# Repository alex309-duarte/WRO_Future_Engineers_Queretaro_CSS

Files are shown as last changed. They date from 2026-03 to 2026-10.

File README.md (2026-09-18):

# CSS - WRO Future Engineers 2026

This repository contains the engineering documentation for **CSS**'s autonomous vehicle for the **WRO Future Engineers**, 2026 season. Our team is based in Querétaro, México.

---

## Table of Contents

1. [Our Team](#our-team)
2. [Challenge Overview](#challenge-overview)
3. [Our Robot](#our-robot)
   - [3.1 Mobility Management](#mobility-management)
   - [3.2 Power & Sense Management](#power-sense-management)
   - [3.3 Obstacle Management & Control Strategy](#obstacle-management)
4. [Engineering Process & Design Iterations](#engineering-process)
5. [Construction Guide](#construction-guide)
6. [Bill of Materials (BOM)](#bom)
7. [Repository Structure](#repository-structure)
8. [Setup & Execution Instructions](#setup-instructions)
9. [Driving Videos](#driving-videos)
10. [Resources & References](#resources)
11. [License](#license)

---

## 1. Our Team 
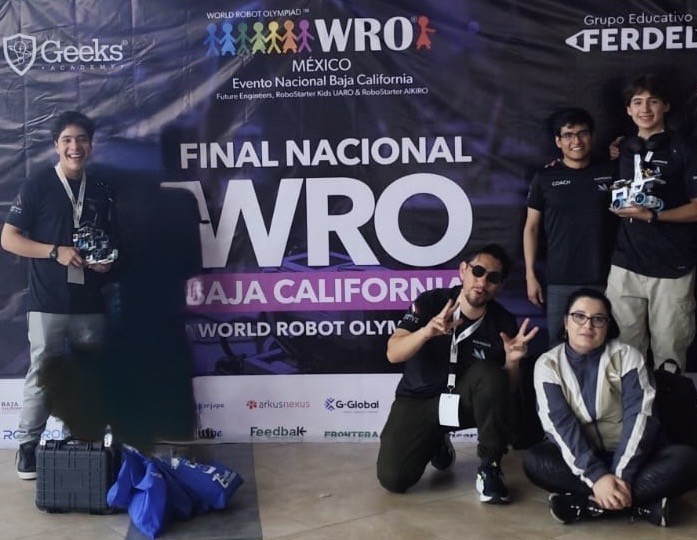
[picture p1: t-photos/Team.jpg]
<br>
***Disclaimer:***
*This image has been edited to remove former team members who are no longer part of the project, in order to protect their privacy. Editing was done using Microsoft Photos' generative erase feature.*

### Team Members

#### Christian Gael Centeno Velez
**Age:** 17\
**Role:** Captain. Software, electronics and mechanical design\
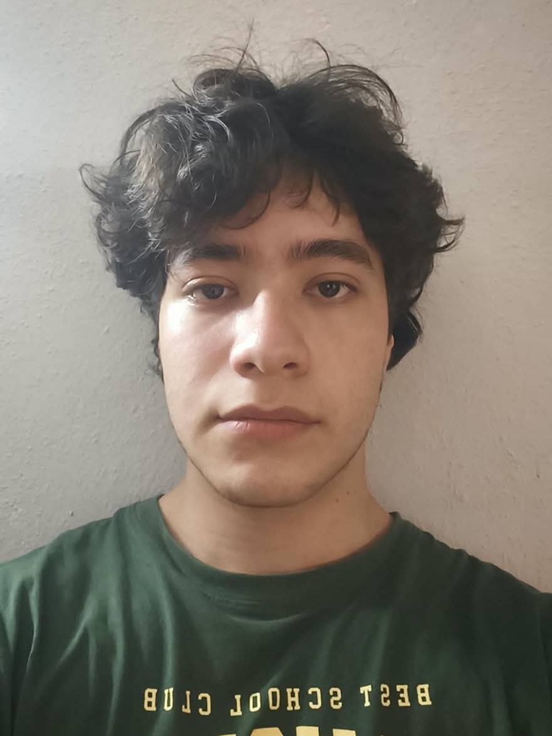
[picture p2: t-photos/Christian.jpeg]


>I am currently in my senior year of high school at the Colegio de Estudios Científicos y Tecnológicos del Estado de Querétaro (CECyTEQ), specializing as a Mechatronics Technician. I have a strong background in competitive robotics, having participated in previous editions of the World Robot Olympiad (WRO). In 2024, I competed in the RoboMission category, and in 2025, I secured third place at the national level in the Future Engineers category. Through my years of experience competing in the WRO, I have developed solid skills in robot programming, design, and electronics.

#### Sebastián Esquivel Mondragón
**Age:** 18\
**Role:** Documentation, electronics and mechanical design\
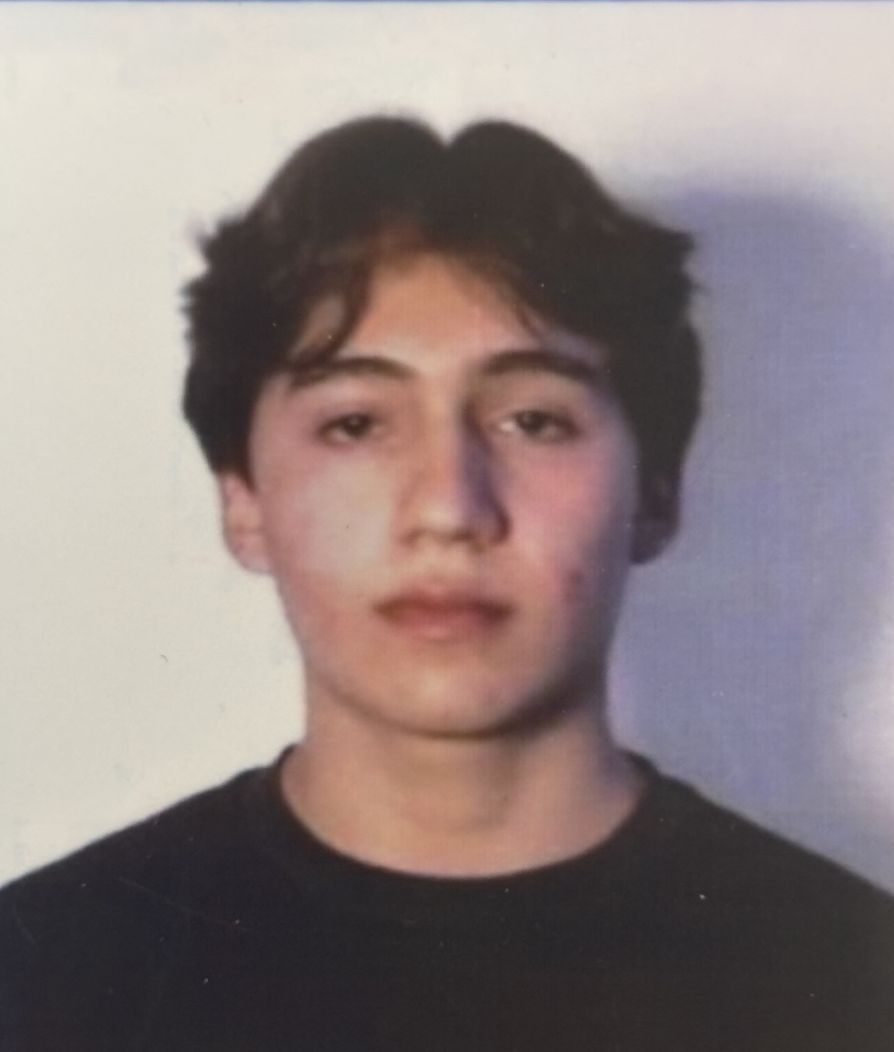
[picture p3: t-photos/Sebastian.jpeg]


> Currently pursuing a Bachelor of Science in Mechatronics Engineering at Monterrey Institute of Technology and Higher Education (ITESM), on an academic talent scholarship. My background in robotics began in middle school with the MekLab Robotics team (UAQ), where I competed in WRO RoboMission, placing 3rd nationally in 2022 (Junior) and 2nd nationally in 2023 (Senior), qualifying for the international final in Panama. In 2025, our now independent and disaffiliated team moved into WRO Future Engineers, placing 2nd nationally. Most of my software and electronics experience comes from these competitions. I've also worked as an intern at GS de México (GS Global), in the Research and Development (R&D) department, where I further developed CAD design skills and many other engineering competencies, such as problem solving skills, now applied towards this project.

---

### Coach and other members

#### Manuel Alejandro Cardoso Duarte
**Age:** 27\
**Role:** Coach\
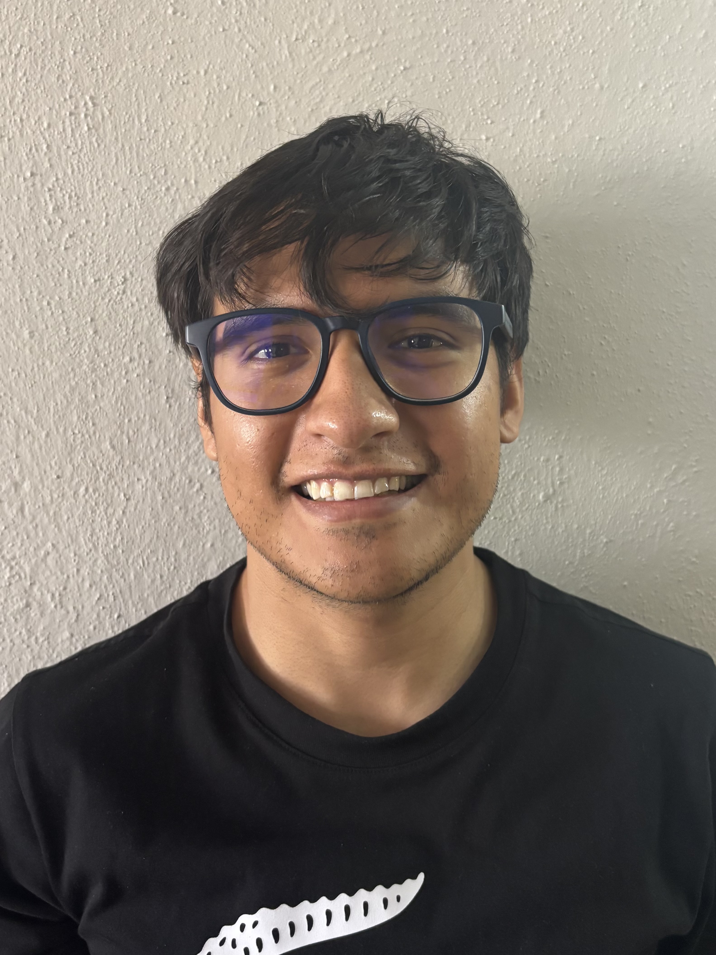
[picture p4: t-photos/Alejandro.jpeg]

> Bachelor of Technology from the Universidad Nacional Autónoma de México (UNAM), Centro de Física Aplicada y Tecnología Avanzada (CFATA), and currently works as an Embedded Software Engineer at KOSTAL Automotive Services Mexicana, developing AUTOSAR-based embedded software (C, CAN/LIN bus communication, memory stack integration) for automotive door control modules serving clients such as Stellantis, FORD, and Rivian. His background in robotics coaching spans since February 2018, guiding high school teams at the Facultad de Ingeniería, Universidad Autónoma de Querétaro (UAQ) through the World Robot Olympiad, including leading our team to the 2023 international final in Panama City and to a national podium finish in RoboMission. As coach, his role is to teach the underlying engineering and programming concepts (Python, C, embedded systems) and guide the team's problem-solving process, without building or programming the vehicle himself. For more information visit: [CV Alejandro](other/additionalMedia/Others/CV_Manuel_Alejandro_Cardoso_Duarte_2026-compressed.pdf)

---

#### José de Jesús Santana Ramírez, M.Sc.
**Age:** 40\
**Role:** Assistant coach\
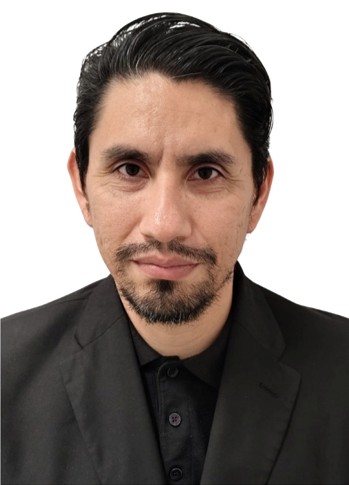
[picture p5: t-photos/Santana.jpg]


>Mechatronics Engineer and Master of Science in Instrumentation and Control, with a solid track record in teaching, technological development, and innovation-oriented engineering applications. Currently pursuing a Ph.D. in Computer Science, focusing on research areas related to artificial intelligence, neural networks, computational modeling of physical systems, and control of mechanical systems. His expertise integrates hardware and software development for robotics, automation, and embedded systems projects. He serves as the coordinator of the Center for Studies in Robotics and Sciences (CEROC) at UAQ, as well as a professor in the Space Engineering degree program at ENES-UNAM. His professional profile is distinguished by connecting academic training, applied research, and a commitment to the scientific and technological education of future generations.
---

#### Rocío Damara Merlo Espino, Ph.D.
**Age:** 36\
**Role:** Administrative project manager\
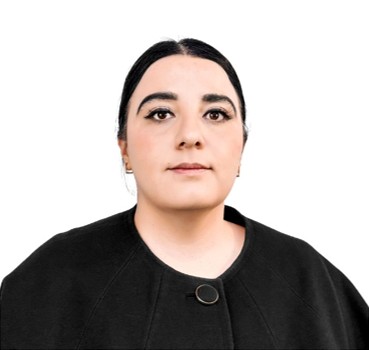
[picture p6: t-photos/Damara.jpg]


>Academic Degrees:
>- Bachelor’s Degree in Psychology, Educational concentration.
>- Specialization in School Learning.
>- Master’s Degree in Innovation in Virtual Teaching-Learning Environments.
>- Ph.D. in Educational Technology.
>
>Professional with a background in Psychology, School Learning, Innovation in Virtual Teaching-Learning Environments, and Educational Technology. She is the co-leader of the international chapter Women in Robotics Querétaro, Mexico, and brings over 12 years of experience in educational robotics, science pedagogy, and scientific outreach. Currently, she is completing a postdoctoral fellowship in Quality Management Systems for Engineering and Space Industry Laboratories at the High Technology Unit of the Faculty of Engineering at UNAM. In addition, she is a professor of Aerospace Engineering at ENES Juriquilla, a researcher, and Head of the Outreach Department at the Center for Studies in Robotics and Sciences (CEROC) at UAQ. She has driven academic, scientific, and technological projects, as well as student development in STEAM competencies.

---

## 2. Challenge Overview 

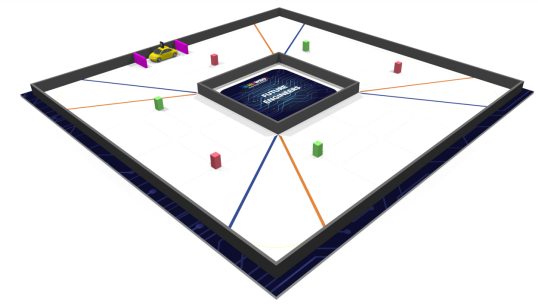
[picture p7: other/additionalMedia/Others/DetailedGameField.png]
Detailed Game Field


The **WRO Future Engineers** challenge requires teams to build a fully autonomous vehicle capable of completing both of the following challenges:

### Open Challenge
The vehicle must complete three laps on the track with random placements of the inside track walls.

### Obstacle Challenge
The vehicle must complete three laps on the track while detecting and avoiding randomly placed coloured obstacles (either green or red blocks), passing them on a specific side according to their colour, and then finish by performing a parallel parking maneuver.

More info: [WRO Official Site](https://wro-association.org/) | [Future Engineers Rules](other/WRO-2026-FE_GeneralRules.pdf)

---

## 3. Our Robot 

**Robot name:** ***"The Maker"***

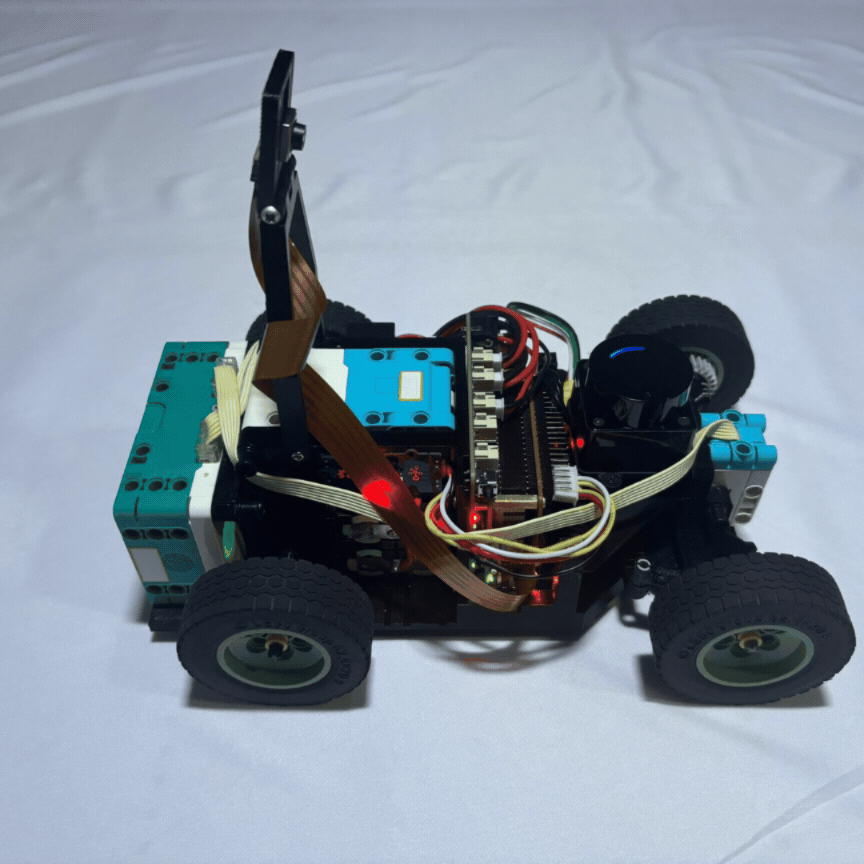
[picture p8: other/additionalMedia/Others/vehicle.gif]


<table style="width:100%">

<tr>

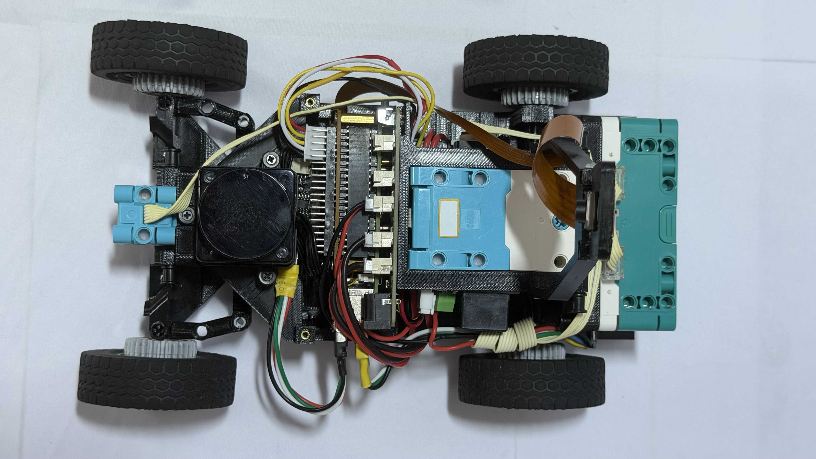
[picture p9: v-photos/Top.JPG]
<td align="center"><br>Top</td>

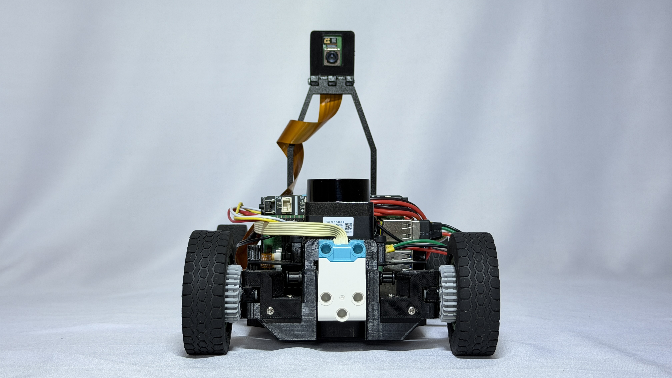
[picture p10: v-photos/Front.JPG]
<td align="center"><br>Front</td>

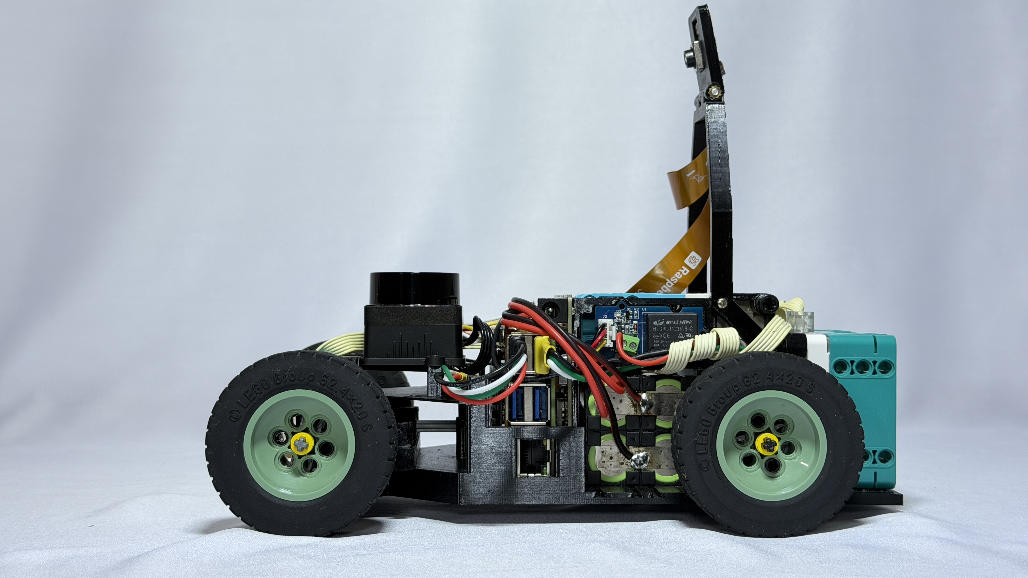
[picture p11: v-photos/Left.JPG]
<td align="center"><br>Left</td>

</tr>

<tr>

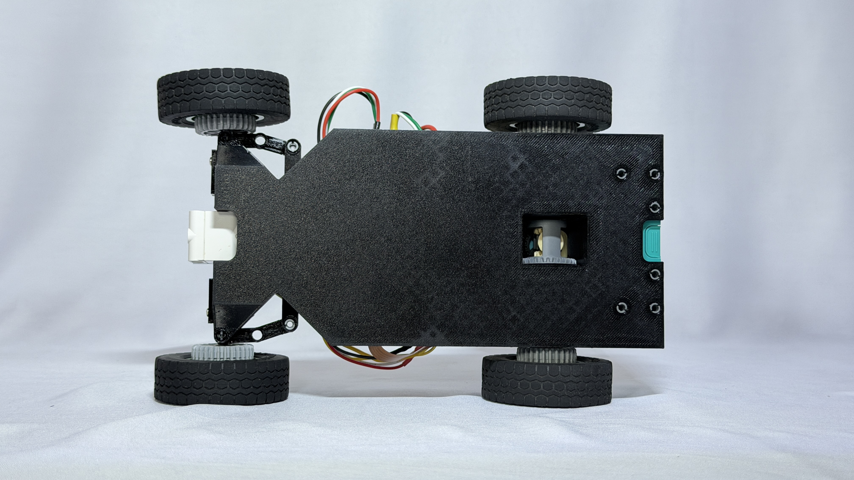
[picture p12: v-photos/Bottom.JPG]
<td align="center"><br>Bottom</td>

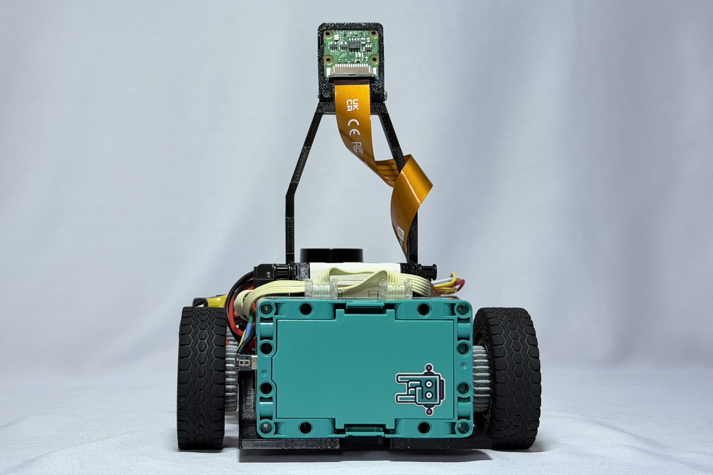
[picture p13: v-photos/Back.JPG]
<td align="center"><br>Back</td>

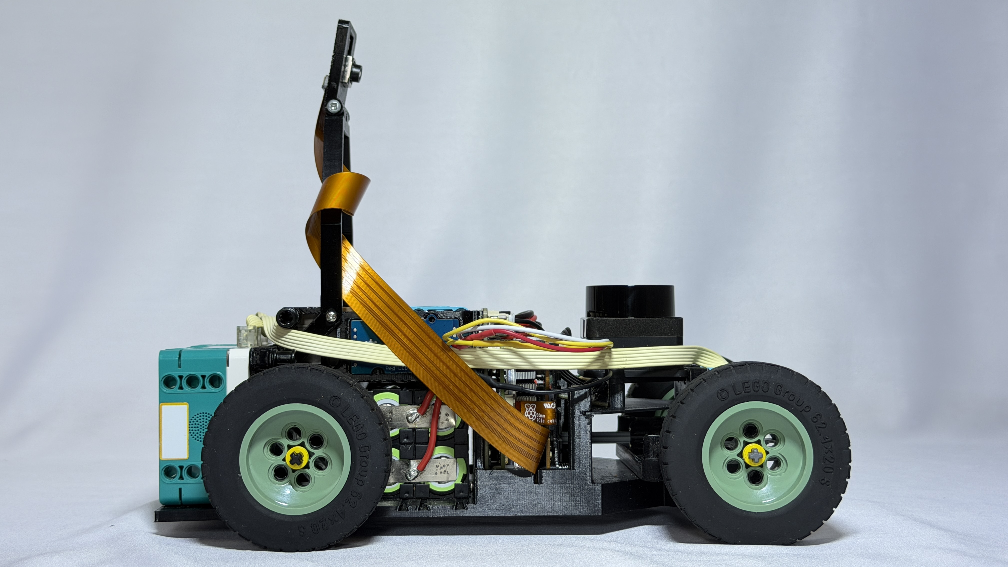
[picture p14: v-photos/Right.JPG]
<td align="center"><br>Right</td>

</tr>

</table>

***"The Maker"*** is a rear-wheel-drive autonomous vehicle built around a fully custom, in-house 3D-printed chassis (designed in SolidWorks, printed on a Creality K1C) that repositions the battery pack and most components lower in the frame to lower the center of gravity and reduce weight transfer through corners. This year's chassis also trades the sharper-turning custom double-Ackermann steering geometry used in last year's prototype for a simpler regular-Ackermann, a deliberate trade-off made after trial and error showed the reliability gain outweighed the small loss in turning radius. A single LEGO SPIKE Large Angular Motor drives the rear axle while a LEGO SPIKE Small Angular Motor actuates the Ackermann steering, both commanded by a LEGO SPIKE Prime Hub, whose built-in IMU also supplies the robot's heading. Perception comes from a Orbbec Oradar MS200k LiDAR fused with a Raspberry Pi Camera Module 3 Wide accelerated by a Raspberry Pi AI HAT+ 2 (Hailo-10H, 40 TOPS). The LiDAR handles wall-following and obstacle range, the camera tracks the obstacles using a custom-trained YOLOv8n model (trained on our own labeled dataset and compiled to the Hailo-10H's `.hef` format) and classifies pillar colour, and this year's design drops the ultrasonic sensors, now using only the LiDAR and camera. All control and vision code runs in C/C++ on a Raspberry Pi 5, migrated from last year's Python codebase specifically to cut processing latency, and the whole robot is considerably lighter and more power-efficient than its predecessor: a smaller steering motor, a lighter AI/camera replacing an OAK-D Lite, and a 4-cell battery pack (down from 6 cells) sized to match the lower power draw.

### 3.1 Mobility Management 

#### Steering System

The Maker's steering uses a regular Ackermann linkage, achieving a maximum steering angle of **45.44°**. This geometry ensures the inner and outer front wheels trace concentric arcs around a common turning center during a turn, minimizing tire scrub and keeping the front tires rolling rather than dragging through corners, a property that matters directly for both consistency and tire wear over a full run.

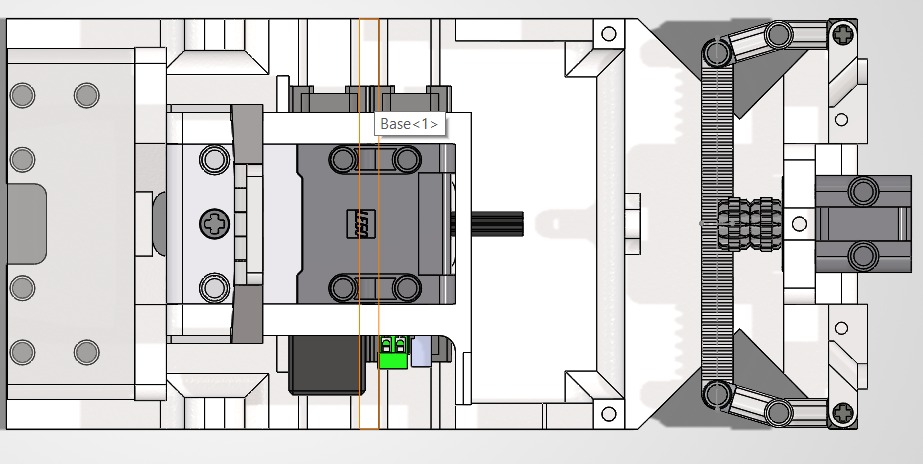
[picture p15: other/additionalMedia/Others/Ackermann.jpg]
Plan view of the current Ackermann steering system CAD model


*Figure 1. Plan view of the current Ackermann steering linkage, showing the tie-rod and knuckle geometry.*

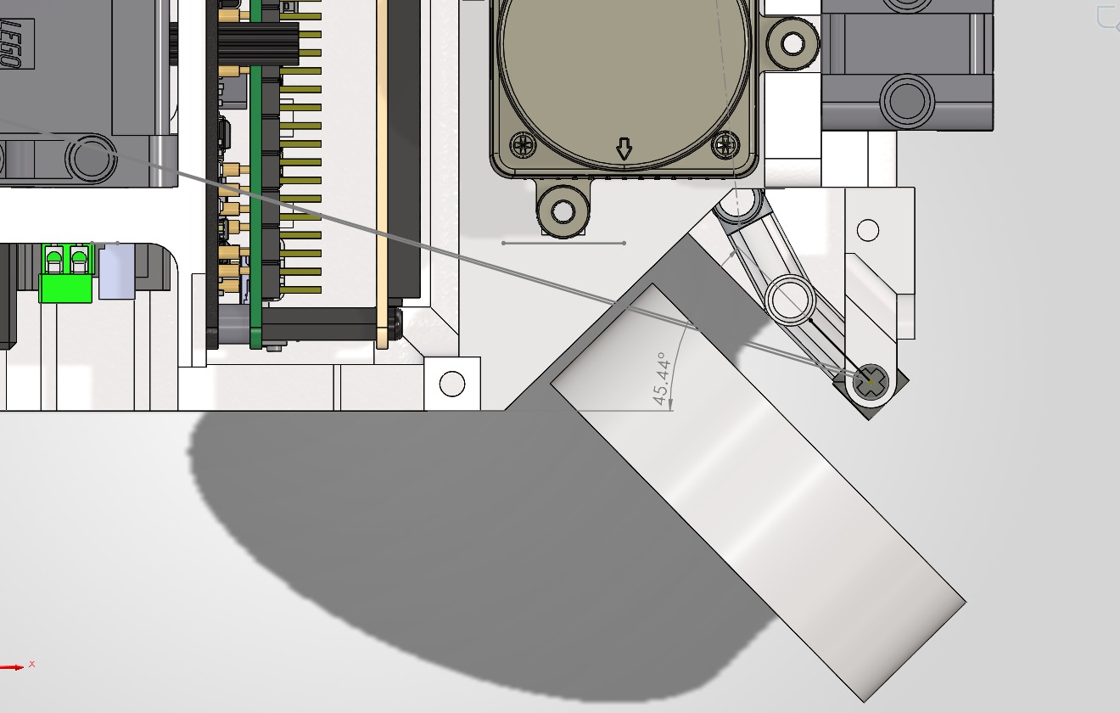
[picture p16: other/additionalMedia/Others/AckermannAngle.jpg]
CAD detail view showing the 45.44 degree Ackermann steering angle


*Figure 2. Detail view of the CAD model highlighting the achieved maximum steering angle of 45.44°.*

The Ackermann is actuated by a LEGO SPIKE Prime Small Angular Motor (Part 45607), commanded by the LEGO SPIKE Prime Hub. This is a change from previous seasons, where a medium angular motor was used: with this year's lighter chassis and reduced overall mass, the torque required to actuate the steering dropped enough that the smaller motor became sufficient, and switching to it freed up both weight and packaging space for other components.

This regular Ackermann design also represents a deliberate step back from last year's steering geometry. In the previous season, the team implemented a custom double-Ackermann linkage, which allowed for a tighter turning radius but introduced mechanical inconsistencies and reliability flaws during testing.

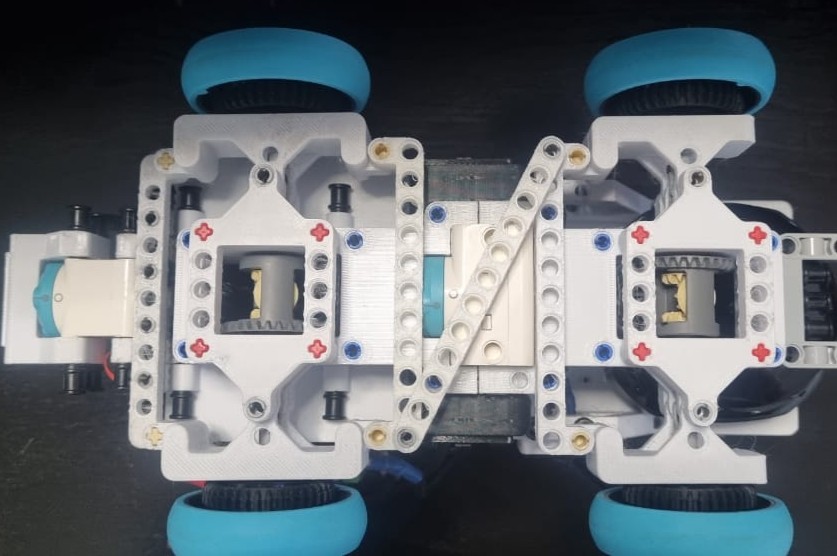
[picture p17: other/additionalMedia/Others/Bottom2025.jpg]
Bottom view of last year's robot showing the double Ackermann steering system


*Figure 3. Bottom view of the previous season's robot, showing the double-Ackermann steering configuration used last year.*

After weighing both options, the team concluded that the regular Ackermann's slightly wider turning radius was an acceptable trade-off given the reliability gained: it consistently completes every required turn on the WRO track, while eliminating the mechanical inconsistencies that affected the double-Ackermann design.

#### Drivetrain

This year's drivetrain also marks a layout change from last year's all-wheel-drive (AWD) configuration (see [Figure 3](other\additionalMedia\Others\Bottom2025.jpg)) to a rear-wheel-drive (RWD) layout. Driving only the rear axle simplified the drivetrain (removing the front differential/driveshaft hardware needed for AWD), reducing weight and mechanical complexity, while still providing enough traction for the WRO track once paired with the new LEGO 62.4×20S rubber tires.

The vehicle uses a single LEGO SPIKE Large Angular Motor (Part 45602) driving the rear axle through a $20{:}28$ gear reduction ($R = 1.4$), turning LEGO $62.4 \times 20\text{S}$ rubber tires (Part 32019) ($r = 0.0312\text{ m}$). The motor and gear ratio were not assumed, they were sized against a full dynamic torque analysis targeting $a = 0.73\text{ m/s}^2$ over $t = 0.5\text{ s}$ to reach cruising speed.
<table>
  <tr>
    <td align="center">
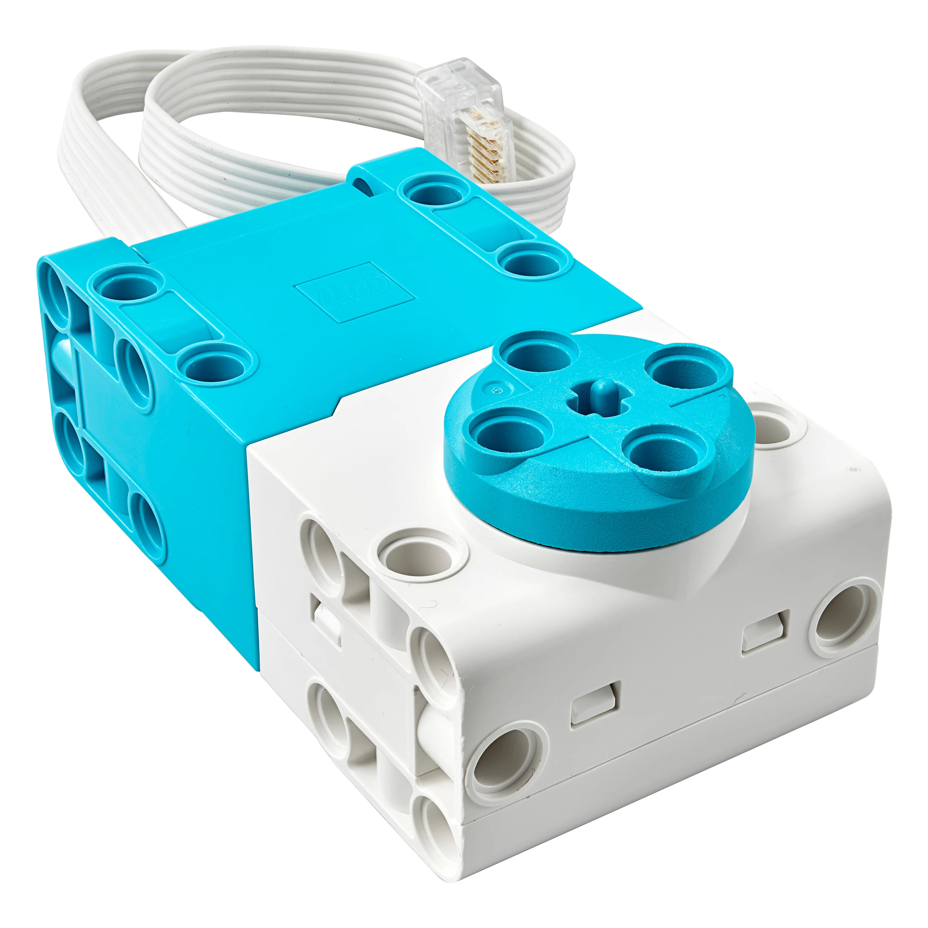
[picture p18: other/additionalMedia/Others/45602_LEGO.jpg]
      <br>
      <em>LEGO SPIKE Large Angular Motor (45602)</em>
    </td>
    <td align="center">
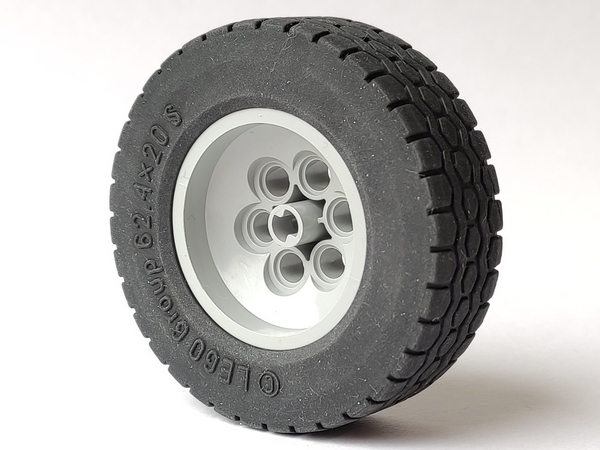
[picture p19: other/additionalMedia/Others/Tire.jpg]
      <br>
      <em>LEGO Tire 62.4 x 20 S (32019)</em>
    </td>
  </tr>
</table>

**Result:**
 at this operating point, the motor runs at only **33.8%** of its continuous max-efficiency torque capacity, reaching a loaded top speed of **0.365 m/s**, leaving a **66.2%** torque reserve for inclines or unexpected track perturbations.

> ### Full torque & speed calculations
>
> #### 1. Design Inputs & Parameters
>
> | Parameter | Symbol | Value | Unit |
> | :--- | :---: | :---: | :---: |
> | Robot Mass | $m$ | $1.006$ | $\text{kg}$ |
> | Wheel Diameter | $d$ | $0.0624$ | $\text{m}$ |
> | Wheel Radius | $r$ | $0.0312$ | $\text{m}$ |
> | Target Linear Acceleration ($t = 0.5\text{ s}$) | $a$ | $0.73$ | $\text{m/s}^2$ |
> | Rolling Resistance Coeff. (Rubber LEGO $62.4 \times 20\text{ S}$) | $C_{rr}$ | $0.03$ | -- |
> | Acceleration of Gravity | $g$ | $9.81$ | $\text{m/s}^2$ |
> | Number of Drive Motors | $N$ | $1$ | -- |
> | Gearbox Reduction Ratio ($20:28$) | $R$ | $1.4$ | -- |
> | Gearbox Efficiency | $\eta$ | $0.85$ | -- |
>
> **2. Step-by-Step Derivation**
>
> **Step 1: Linear Acceleration Force ($F_{acc}$)**
>
> $$
> F_{acc} = m \cdot a = 1.006\text{ kg} \cdot 0.73\text{ m/s}^2 = 0.7344\text{ N}
> $$
>
> **Step 2: Rolling Resistance Force ($F_{rr}$)**
>
> $$
> F_{rr} = C_{rr} \cdot m \cdot g = 0.03 \cdot 1.006\text{ kg} \cdot 9.81\text{ m/s}^2 = 0.2961\text{ N}
> $$
>
> **Step 3: Total Linear Force ($F_{total}$)**
>
> $$
> F_{total} = F_{acc} + F_{rr} = 0.7344\text{ N} + 0.2961\text{ N} = 1.0305\text{ N}
> $$
>
> **Step 4: Total Wheel Torque ($T_w$)**
>
> $$
> T_w = F_{total} \cdot r = 1.0305\text{ N} \cdot 0.0312\text{ m} = 0.03215\text{ N}\cdot\text{m}
> $$
>
> **Step 5: Nominal Motor Torque ($T_m$)**
>
> $$
> T_m = \frac{T_w}{\eta \cdot R} = \frac{0.03215\text{ N}\cdot\text{m}}{0.85 \cdot 1.4} = 0.02702\text{ N}\cdot\text{m} \quad (\approx 2.70\text{ Ncm})
> $$
>
> **Step 6: Motor Torque with Safety Factor ($T_{m,req}$)**
>
> A 25% safety margin ($1.25\times$) is applied to establish the minimum required torque of the traction motor, accounting for dynamic losses not captured above:
>
> $$
> T_{m,req} = T_m \cdot 1.25 = 0.02702\text{ N}\cdot\text{m} \cdot 1.25 = \mathbf{0.03377\text{ N}\cdot\text{m}} \quad (\approx 3.38\text{ Ncm})
> $$
>
> **3. LEGO SPIKE Large Angular Motor (45602) Analysis & Speed Derivation**
>
> **3.1 Motor Technical Specifications (9V)**
>
> | Operating Condition | Torque ($\text{N}\cdot\text{m}$) | Torque ($\text{Ncm}$) | Speed ($\text{RPM}$) | Current ($\text{mA}$) |
> | :--- | :---: | :---: | :---: | :---: |
> | No Load | 0.0000 | 0.00 | 175 ± 15% | 135 ± 15% |
> | Max Efficiency | 0.0800 | 8.00 | 135 ± 15% | 430 ± 15% |
> | Stall Limit | 0.2500 | 25.00 | 0 | 1900 ± 15% |
>
> **3.2 Motor Operating Point & Load Analysis**
>
> **Continuous Duty Load (%)** (vs. Max Efficiency Point):
>
> $$
> \text{Load}_{\text{eff}} = \frac{T_m}{T_{\text{max-eff}}} \cdot 100 = \frac{2.70\text{ Ncm}}{8.00\text{ Ncm}} \cdot 100 = \mathbf{33.8}\verb|%|
> $$
>
> **Stall Limit Margin (%)** (vs. Stall Torque):
>
> $$
> \text{Load}_{\text{stall}} = \frac{T_m}{T_{\text{stall}}} \cdot 100 = \frac{2.70\text{ Ncm}}{25.00\text{ Ncm}} \cdot 100 = \mathbf{10.8}\verb|%|
> $$
>
> **3.3 Top Speed Derivation**
>
> **Step 1: Loaded Motor RPM**
>
> $$
> \text{RPM}_{\text{motor}} = \text{RPM}_{\text{no-load}} \cdot \left(1 - \frac{T_m}{T_{\text{stall}}}\right) = 175 \cdot \left(1 - \frac{2.702\text{ Ncm}}{25.00\text{ Ncm}}\right) = 156.1\text{ RPM}
> $$
>
> **Step 2: Loaded Wheel RPM**
>
> $$
> \text{RPM}_{\text{wheel}} = \frac{\text{RPM}_{\text{motor}}}{R} = \frac{156.1\text{ RPM}}{1.4} = 111.5\text{ RPM}
> $$
>
> **Step 3: Top Loaded Linear Speed**
> $$v_{loaded} = \frac{\text{RPM}_{wheel} \cdot \pi \cdot d}{60} = \frac{111.5 \cdot \pi \cdot 0.0624}{60} = \mathbf{0.365\text{ m/s}}$$
>
> **3.4 Technical Conclusion**
>
> With $a = 0.73\text{ m/s}^2$, the robot reaches its operational cruising speed of $0.365\text{ m/s}$ in exactly $0.5\text{ s}$. Operating at only 33.8% of the motor's continuous max-efficiency capacity ensures minimal thermal build-up and low current draw, leaving a 66.2% torque reserve to absorb unexpected track perturbations.

#### Chassis Design

The chassis is a fully custom, in-house design, modeled in SolidWorks and 3D-printed on a Creality K1C. This is a continuation of the team's own-design approach from previous years, refined for this iteration to package the electronics more densely and lower the center of gravity, positioning the battery pack and most of the main components lower in the frame.

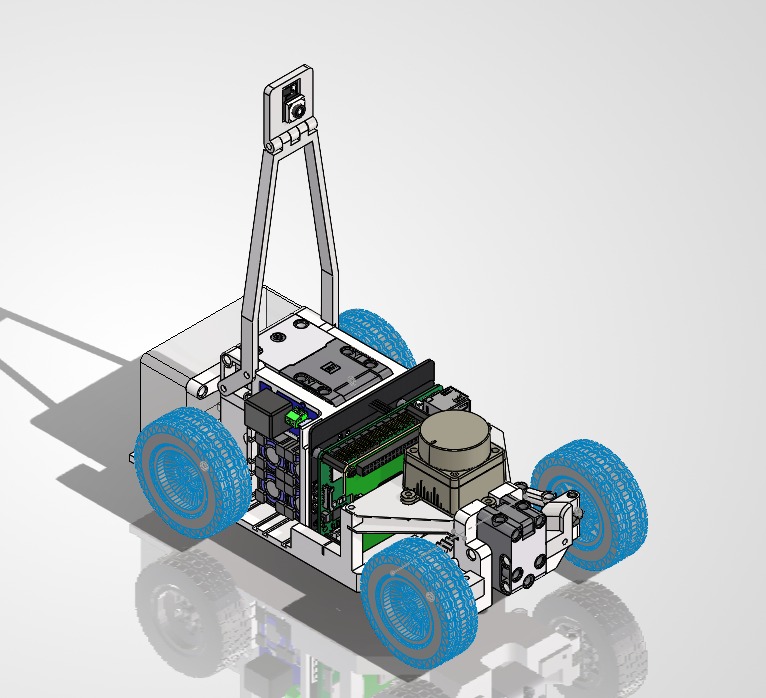
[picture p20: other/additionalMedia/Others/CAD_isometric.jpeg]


*Figure 4. Isometric view of the current chassis CAD model.*

#### Assembly & Balance

Repositioning the battery pack and heavier components (Raspberry Pi 5, UPS shield, LiDAR) lower in the frame was a deliberate choice to lower the chassis's center of gravity, reducing lateral weight transfer during high-speed cornering and improving mechanical traction without altering the Ackermann geometry itself. Component placement was also driven by the switch to a smaller, lighter camera/AI stack (Hailo-10H + Camera Module 3 Wide, replacing the OAK-D Lite) and a lighter 2-cell battery pack (replacing the previous 3-cell pack), both of which reduced overall mass and allowed tighter, more balanced packaging than in previous prototypes.

---

### 3.2 Power & Sense Management 

### Sensors & Perception Units

---

**Orbbec Oradar MS200k LiDAR**
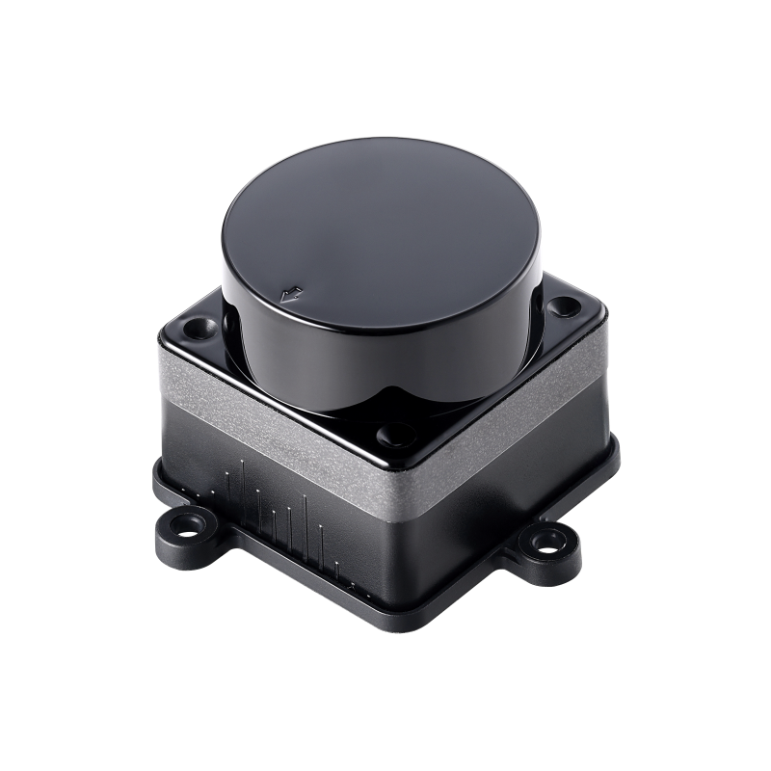
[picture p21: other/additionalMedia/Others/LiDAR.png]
<br><br>
Provides a 360° distance scan around the robot, used for wall-following (perpendicular distance and orientation of the walls relative to the robot) and for measuring range to obstacles once they've been located by the camera. It replaces last year's Slamtec RPLiDAR S2L: after trial and error, it was chosen for being lighter and giving more reliable, less noisy distance readings. It connects to the Raspberry Pi 5 and feeds the wall-detection/line-fitting logic that drives the robot's navigation decisions.

---

**Raspberry Pi Camera Module 3 Wide + Raspberry Pi AI HAT+ (Hailo-10H, 40 TOPS)**
<table>
  <tr>
    <td align="center">
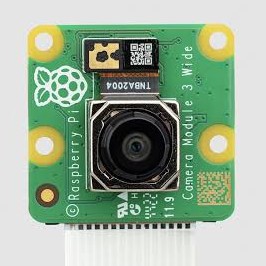
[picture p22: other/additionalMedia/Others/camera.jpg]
      <br>
      <em>Raspberry Pi Camera Module 3 Wide</em>
    </td>
    <td align="center">
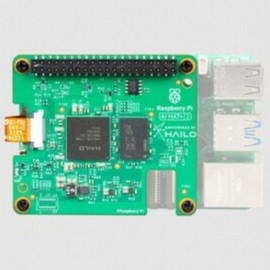
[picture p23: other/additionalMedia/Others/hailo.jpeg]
      <br>
      <em>Raspberry Pi AI HAT+ 40 TOPS (Hailo-10H)</em>
    </td>
  </tr>
</table>
The camera captures the visual feed used to detect obstacle pillars and classify their color (red/green), while the Hailo-10H accelerator runs a custom-trained YOLOv8n model on-device to perform that detection/classification in real time. This pairing replaces last year's OAK-D Lite, chosen to reduce weight, power consumption, and response (inference) time while increasing overall efficiency. The camera's detections are fused with the LiDAR's distance data: the camera identifies what an obstacle is and roughly where, and the LiDAR supplies the precise distance needed to compute an avoidance vector.

---

**LEGO SPIKE Prime Hub (built-in IMU)**
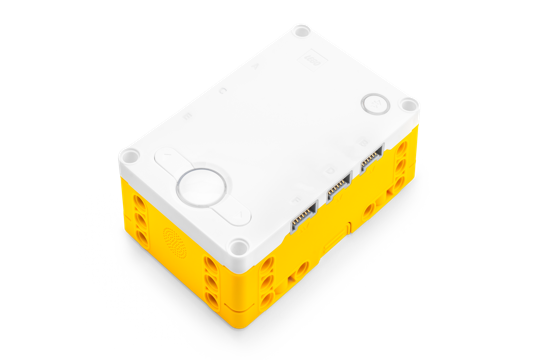
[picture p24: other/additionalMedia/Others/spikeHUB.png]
<br><br>
Rather than using a separate IMU module, the team relies on the SPIKE Prime Hub's built-in IMU to supply the robot's heading/orientation. The hub communicates with the Raspberry Pi 5 over a serial link, both relaying IMU readings and receiving motor commands for the drivetrain and steering.

---
### **(REMOVED)**
**Ultrasonic sensors**
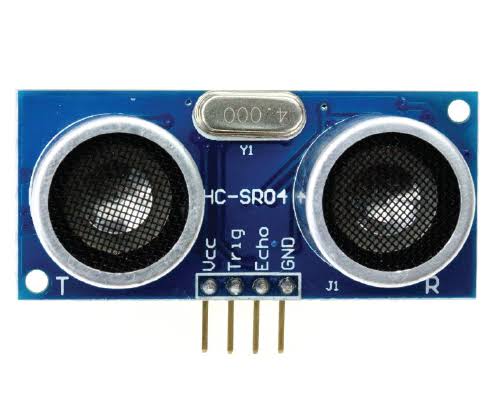
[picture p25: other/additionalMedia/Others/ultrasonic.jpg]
<br><br>
Ultrasonic sensors used in previous seasons were removed this year; the robot now relies entirely on the LiDAR and camera for perception, simplifying the sensor suite and reducing weight/power draw.

---

### Power Management

The robot is powered by 4x Panasonic NCR18650B 3400mAh Li-ion cells (3.6 V nominal each), wired in a 4P (four cells in parallel) configuration through the Geekworm X1203 UPS shield, which also boost-converts the output to the 5.1 V required by the Raspberry Pi 5 and peripherals.

**Total stored energy**

$$C_{\text{total}} = 4 \cdot 3400\text{ mAh} = 13.6\text{ Ah}$$

$$E_{\text{total}} = 13.6\text{ Ah} \cdot 3.6\text{ V} = 48.96\text{ Wh}$$

**Theoretical battery life (worst case)**

Under peak load, SLAM navigation and continuous computer vision inference, the components' estimated continuous power draw is:

| Component | Operating State | Estimated Power |
| :--- | :--- | :--- |
| Raspberry Pi 5 | High CPU / OS load | 9.0 W |
| Hailo-10H AI HAT | Active neural network inference | 4.0 W |
| Orbbec Oradar MS200k LiDAR | Continuous scanning with spinning motor | 1.5 W |
| Grove Modules | Relay (short pulses) + LED Button | 0.1 W |
| **Total Load** | **Peak consumption at 5.1 V** | **14.6 W** |

Accounting for the X1203 boost converter's ~90% efficiency ($\eta = 0.90$):

$$P_{\text{input}} = \frac{14.6\text{ W}}{0.90} \approx 16.22\text{ W}$$

$$I_{\text{battery}} = \frac{16.22\text{ W}}{3.6\text{ V}} \approx 4.51\text{ A}$$

> **Hardware Design Note:** Distributed across 4 parallel cells, this is an average of 1.13 A per cell, well within the NCR18650B's 4.8 A continuous discharge limit, avoiding thermal stress and premature degradation.

$$t_{\text{runtime}} = \frac{48.96\text{ Wh}}{16.22\text{ W}} \approx 3.01\text{ hours}$$

**Real-world battery life (measured)**

Physical testing recorded a steady current draw of 0.667 A per connector (each connector groups two cells in parallel), totaling 1.334 A at 5 V across the full integrated system.

$$P_{\text{output}} = 1.334\text{ A} \cdot 5\text{ V} = 6.67\text{ W}$$

$$P_{\text{input}} = \frac{6.67\text{ W}}{0.90} \approx 7.41\text{ W}$$

$$t_{\text{runtime}} = \frac{48.96\text{ Wh}}{7.41\text{ W}} \approx 6.6\text{ hours}$$

> **Conclusion:** Under real-world operating conditions, the robot runs continuously for approximately 6.5 hours before fully depleting the battery bank, well above the theoretical worst-case estimate, since sustained peak CPU/inference load is rarely held continuously in practice.

**Design limitation: charging & hot-swapping**

A drawback of this configuration is that the batteries charge internally, in place, via the X1203 board. The current assembly makes keeping a pre-charged spare set for a quick hot-swap impractical, since swapping cells requires partially disassembling the chassis, a depleted robot must instead be plugged in to recharge, which is a limitation for quick turnaround between test/competition runs.

---

### Processing Architecture & Microcontrollers

The robot's control loop is centered on the Raspberry Pi 5, which fuses two independent sensor streams and issues motor commands accordingly. The Orbbec Oradar MS200k LiDAR streams a 360° distance scan over serial, feeding the wall-following and obstacle-range logic. In parallel, the Raspberry Pi Camera Module 3 Wide streams frames that are run through a custom-trained YOLOv8n model accelerated by the Hailo-10H AI HAT, detecting obstacle pillars and classifying their color. The Raspberry Pi 5 fuses both streams (camera identifies *what* and roughly *where*, LiDAR gives the precise distance) and, running all control and vision code in C/C++ for low latency, computes the next steering/drive action.

Motor and steering commands are sent over a serial (USB) link to the LEGO SPIKE Prime Hub, which actuates the Large Angular Motor (drivetrain) and Small Angular Motor (steering). The Hub's built-in IMU also reports heading back to the Raspberry Pi 5, closing the loop for orientation-aware navigation. Separately, the Raspberry Pi's GPIO pins handle the start button, status LED, and a relay that powers the SPIKE Hub on at boot, these run independently of the main sensor/control loop.

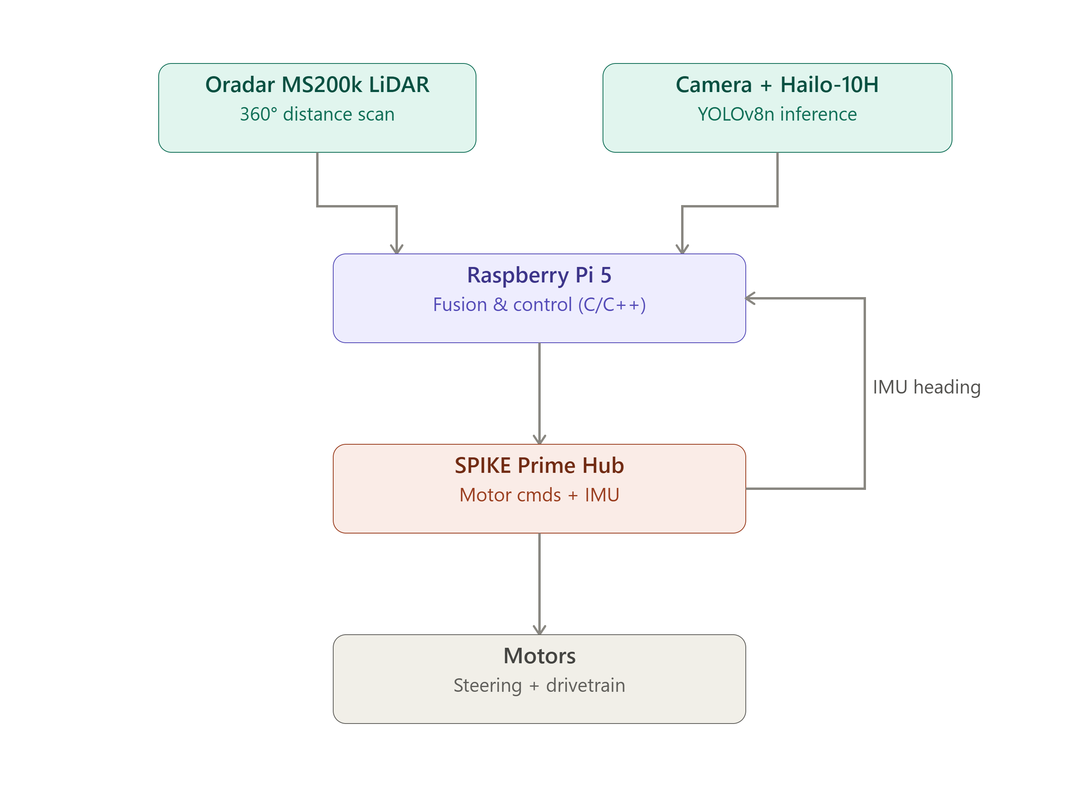
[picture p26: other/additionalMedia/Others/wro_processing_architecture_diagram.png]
Diagram of how the LiDAR, camera, Hailo-10H, Raspberry Pi 5, SPIKE Prime Hub, and motors are interconnected


*Figure 5. Data flow between the robot's sensors, processing units, and actuators.*

---

### Hardware Schematics & PCB Design

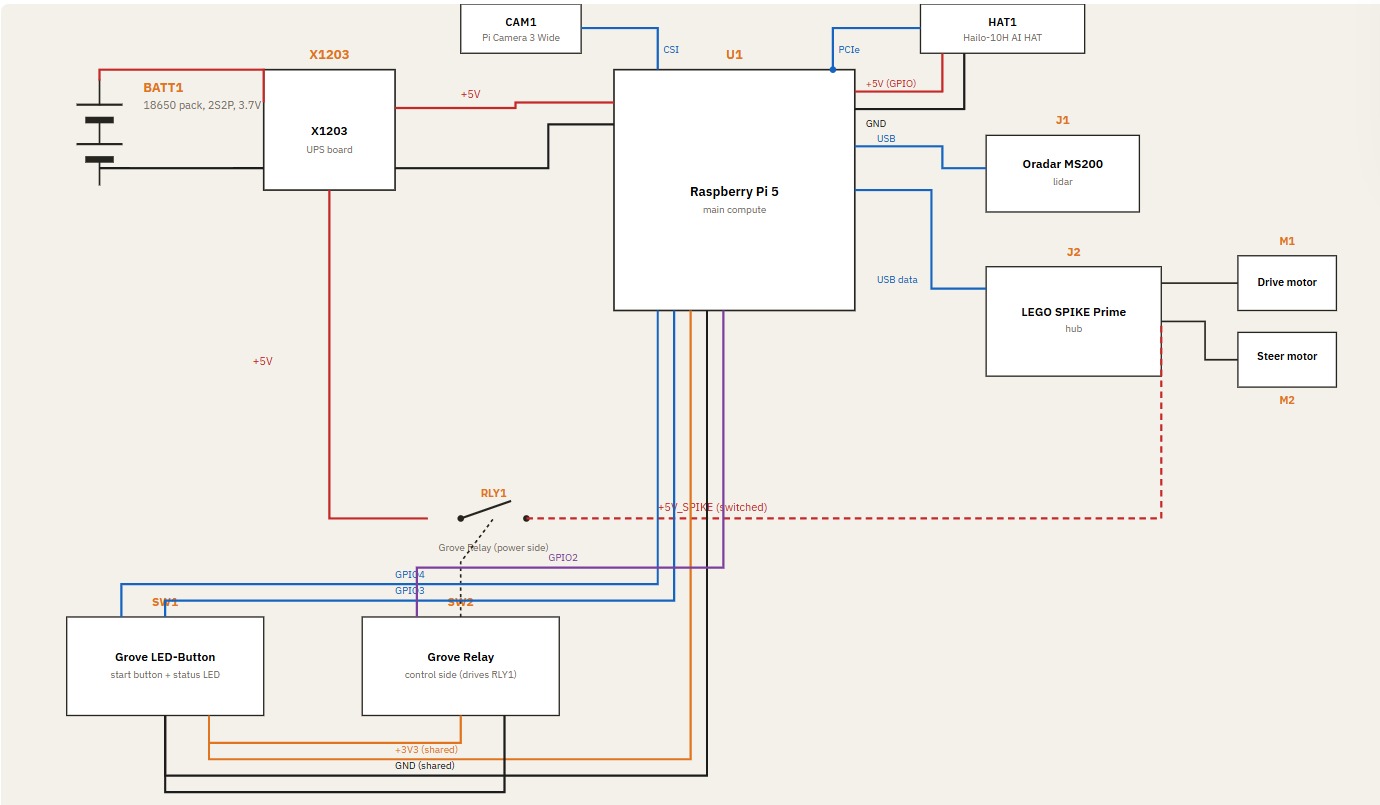
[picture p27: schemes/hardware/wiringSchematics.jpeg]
Connections Schematics


*Figure 6. System wiring diagram showing power distribution (Geekworm X1203 UPS board from the 2S2P 18650 battery pack) and data connections between the Raspberry Pi 5, Camera Module 3 Wide (CSI), Hailo-10H AI HAT (PCIe), Oradar MS200 LiDAR (USB), LEGO SPIKE Prime hub (USB, driving the drive and steer motors), the GPIO-controlled start button/status LED (Grove LED-Button), and the Grove Relay that switches 5V power to the SPIKE hub.*

No custom PCB was implemented in this prototype; the full system wiring is documented in the connections schematic above (*Figure 6*), and all components are connected via their stock breakout boards/shields (Geekworm X1203, Grove modules, etc.) and standard wiring. Schematics for a custom PCB are still in development and not yet implemented in the robot; they are kept at [`schemes\hardware\pcb`](schemes/hardware/pcb) and may be adopted in a future revision if the team qualifies for the international stage. 

---

### Wireless Communication & Telemetry

During development, the team connects to the Raspberry Pi 5 primarily over SSH, occasionally through RealVNC Viewer when a full graphical display is needed, or through a direct terminal connection when the display is not required. This is normally done wirelessly for convenience during testing.

However, since the WRO Future Engineers competition prohibits wireless connections to the robot, the team connects via a wired Ethernet connection instead during the competition itself, to remain compliant with that rule while still allowing SSH access for setup and debugging between runs.

---

### 3.3 Obstacle Management & Control Strategy 



#### System & Software Architecture

All control and vision code runs in C++ on the Raspberry Pi 5, paired with the Hailo-10H AI HAT for on-device inference. The main application (`object_detection`) is structured as a set of cooperating threads: a Hailo preprocess → inference → postprocess pipeline handling camera frames, a background Oradar lidar reader thread continuously filling a 360-slot distance buffer, and an `Obstacle_Challenge_Thread` that runs the navigation/avoidance decision logic and issues motor commands over serial to the LEGO SPIKE Prime Hub.

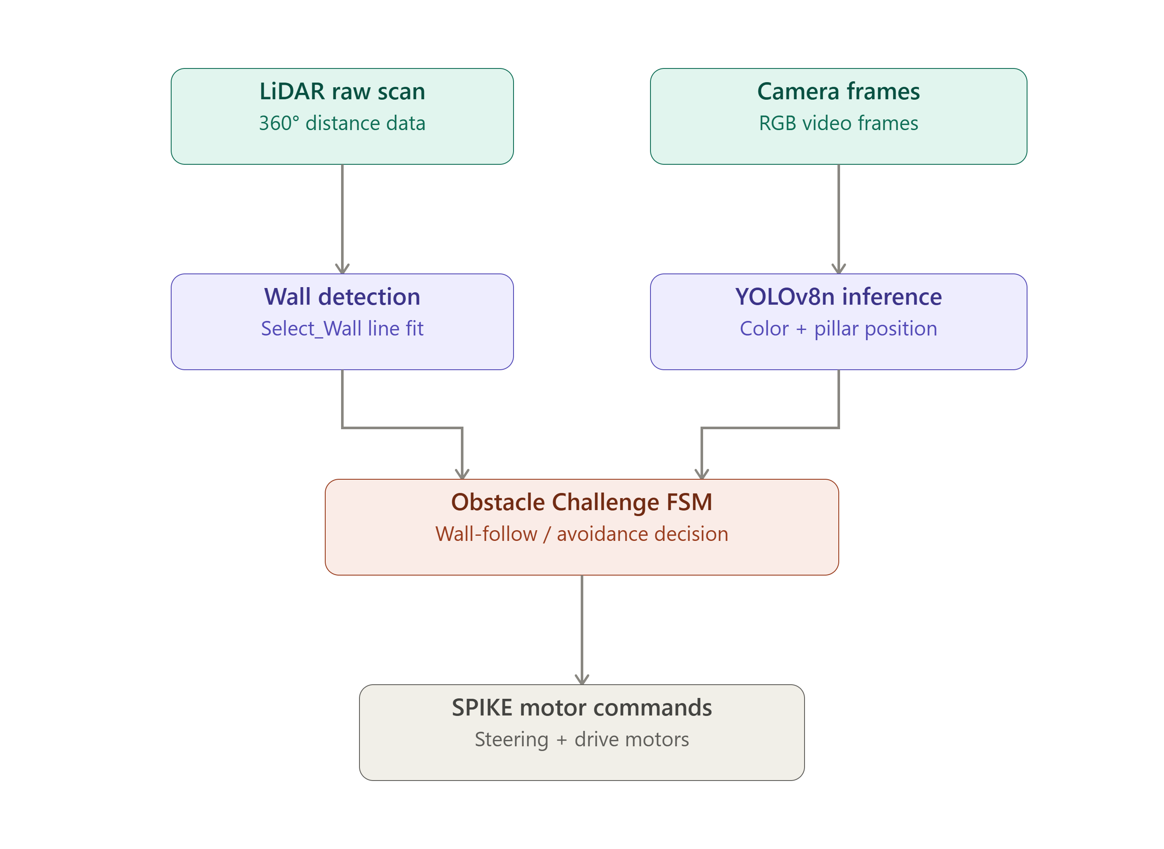
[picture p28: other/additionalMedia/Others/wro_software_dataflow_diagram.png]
Software data flow diagram: sensors, processing, decision, and actuators


*Figure 7. Software data flow from sensor input through processing and decision-making to motor actuation.*

## Open Challenge Program Flow

Unlike the Obstacle Challenge, the Open Challenge runs a separate, simpler program [`src\ondevice\main.cpp`](src/ondevice/main.cpp). There are no color pillars to detect, so the Hailo/camera pipeline isn't used at all, only the LiDAR and the SPIKE Prime Hub. The trace below follows `main()` top to bottom. The robot's own left/right turns are true mirror images of each other in the code, drawn once here as `sentido` (the detected open side), with the mirror called out in the caption below.

```mermaid
flowchart TD
    A(["Power on"]) --> B["Init lidar + writer thread<br/>Init GPIO, power on SPIKE hub<br/>SPIKE serial + interpreter,<br/>load on-hub motion routines"]
    B --> C{{"Wait for start button"}}
    C --> D["Reset gyro to 0&deg;<br/>Center vehicle"]
    D --> E["Read lidar once:<br/>front / right / left distance"]
    E --> F{"right or left<br/>&gt; 800&nbsp;mm?"}
    F -- yes: OUTSIDE start --> G["First straight = 1350&nbsp;mm"]
    F -- no: INSIDE start --> H["First straight = 300&nbsp;mm"]
    G --> I["Detect which side is open:<br/>Advance_And_Detect_Side()<br/>&rarr; sentido = right | left"]
    H --> I
    I --> J["Turn 80&deg; toward sentido<br/>Center vehicle"]
    J --> K["Drive the first-straight distance,<br/>curving toward sentido"]
    K --> L["Slope() at +300&nbsp;mm,<br/>Slope() again at +700&nbsp;mm more"]
    L --> M["Average the two slopes<br/>Reset gyro to that heading"]
    M --> N(["Corner loop<br/>v = 0 &hellip; 9"])
    N --> O["Advance until a gap opens<br/>on the sentido side"]
    O --> P["Turn 80&deg; toward sentido<br/>Center vehicle"]
    P --> Q["Drive 300&nbsp;mm, then 700&nbsp;mm more,<br/>measuring + averaging slope again"]
    Q --> R["Reset gyro to the new heading"]
    R --> S{"v = 10?"}
    S -- "no (v&plus;&plus;)" --> N
    S -- yes --> T["Pick a stop distance from the<br/>opposite-side reading taken back<br/>at the start (400 / 600&nbsp;mm bands)"]
    T --> U["Turn 80&deg; toward sentido, center<br/>Drive 300&nbsp;mm"]
    U --> V{"front reading<br/>&gt; 1500&nbsp;mm?"}
    V -- yes --> W1["Advance to 1750&nbsp;mm from wall"]
    V -- no --> W2["Advance to 1400&nbsp;mm from wall"]
    W1 --> X["Coast motors &middot; close serial<br/>stop lidar thread &middot; close lidar"]
    W2 --> X
    X --> Z(["Run finished"])
```

*Figure 8. Open Challenge program flow, traced directly from [`src\ondevice\main.cpp`](src/ondevice/main.cpp).*

> Every turn, distance, and threshold above is read directly out of [`main.cpp`](src/ondevice/main.cpp). **Sentido** (the detected open side) is fixed for the whole run right after the first turn, the code for `sentido = left` is the exact sign-mirrored twin of the `right` path drawn here.

### High-Level States

The same run, one level up, the states a judge or teammate would actually watch the robot move through.

```mermaid
stateDiagram-v2
    [*] --> Booting
    Booting --> WaitingForStart: hardware + hub ready
    WaitingForStart --> Calibrating: start button pressed
    Calibrating --> SideDetect: gyro zeroed, vehicle centered
    SideDetect --> Aligning: open side found (left / right)
    Aligning --> Cornering: heading corrected to wall
    Cornering --> Aligning: gap found, turned (x10)
    Cornering --> Parking: 10th corner cleared
    Parking --> Stopped: final wall reached
    WaitingForStart --> Stopped: Ctrl+C
    Calibrating --> Stopped: Ctrl+C
    SideDetect --> Stopped: Ctrl+C
    Aligning --> Stopped: Ctrl+C
    Cornering --> Stopped: Ctrl+C
    Stopped --> [*]
```

*Figure 9. Open Challenge high-level state machine.*

> Ctrl+C sets the lidar's `terminating` flag from every state; the current busy-wait loop notices it within ~1 ms and the run drops straight to **Stopped** instead of finishing the maneuver in progress.

### Thresholds

Pulled straight from the constants in [`main.cpp`](src/ondevice/main.cpp), for whoever tunes this next.

| Constant | Value | Where it acts |
|---|---|---|
| Outside / inside split | `800 mm` | Right or left reading above this at the very start, treated as an "outside" starting box, else "inside". |
| First straight, outside case | `1350 mm` | Distance driven right after the first turn, before the first slope measurement. |
| First straight, inside case | `300 mm` | Same step, shorter start, inside boxes give less room before the first wall. |
| Slope sampling gap | `300 + 700 mm` | Two `Slope()` reads this far apart get averaged into one heading correction. |
| Corners per run | `10 (v < 10)` | Loop count for the corner-navigation phase, matches the Open Challenge's three laps of the four-cornered field. |
| Corner turn angle | `80°` | Every `Spike_Turn_For_Degrees` call at a corner, in both the lap loop and the setup turn. |
| Final approach bands | `400 / 600 mm` | The opposite-side reading from step 1 selects a 550, 750, or 1050 mm stop distance for parking. |
| Final front threshold | `1500 mm` | Chooses whether the closing approach stops at 1400 or 1750 mm from the front wall. |

---
## Obstacle Challenge flow

Two threads run at once (both started from `main()`): the Hailo camera
pipeline keeps the global `traffic_lights` struct (color, x-position, area,
confidence) updated in the background, while `Obstacle_Challenge_Thread`
drives the robot and reads that struct whenever it needs to know what cube
it's currently looking at. The diagrams below are the navigation thread.

### High-level states

```mermaid
stateDiagram-v2
    [*] --> Booting
    Booting --> WaitingForStart: lidar + GPIO + Spike + Hailo model ready
    WaitingForStart --> InitialScan: start button pressed
    InitialScan --> ClockwiseRun: right-side reading > 600mm
    InitialScan --> CounterClockwiseRun: left-side reading > 600mm
    ClockwiseRun --> ExitParkingLot: estacionamiento_clockwise()
    CounterClockwiseRun --> ExitParkingLot: estacionamiento_counterclockwise()
    ExitParkingLot --> CornerCycle
    CornerCycle --> CornerCycle: x12 total -- 3 laps x 4 corners (4th of each lap runs parking=true)
    CornerCycle --> Idle: 12 corners complete
    Idle --> Stopped: Ctrl+C
    WaitingForStart --> Stopped: Ctrl+C
    InitialScan --> Stopped: Ctrl+C
    CornerCycle --> Stopped: Ctrl+C
    Stopped --> [*]
```

> The direction of the run is fixed for the whole attempt by the single
> side-wall reading taken in `InitialScan`, and both branches feed the same
> `ExitParkingLot` &rarr; `CornerCycle` sequence. The counter-clockwise path is
> the sign-mirrored twin of the clockwise one, so the corner cycle below is
> drawn once rather than twice.

### One corner cycle (repeats x12)

`Corner_Case` and `Desicion` together are the unit that repeats 12 times.
Drawn once here rather than 12 times over.

```mermaid
flowchart TD
    A(["Corner_Case(past_cube, parking)"]) --> B["Advance to 1100mm from the front wall"]
    B --> C["Read the cube color the camera<br/>currently sees: traffic_lights.light_color"]
    C --> D{"cube color?"}
    D -- green --> E["Advance to 600mm (parking)<br/>or 400mm (not parking)"]
    D -- red --> F["Advance to 990mm"]
    D -- none --> G["Advance to 650mm<br/>set is_middle_case from the PREVIOUS cube's color"]
    E --> H["Turn 86&deg; into the next section<br/>(right clockwise, left counter-clockwise),<br/>center vehicle, coast"]
    F --> H
    G --> H
    H --> I(["Desicion(cube, is_middle_case, parking)"])
    I --> J["Sleep 1s, then Slope() on the outer wall<br/>reset gyro +/-90deg to square up to the side wall"]
    J --> K{"was a cube already<br/>seen right at the corner?"}
    K -- "no (color was none)" --> L{"is_middle_case?"}
    L -- yes --> M["esquivar_cubos_middle(parking)<br/>one cube in the middle of the section"]
    L -- no --> N["esquivar_cubos_1(parking)<br/>avoid the first cube"]
    N --> O["esquivar_cubos_2(result, parking)<br/>look for + avoid a second cube"]
    K -- yes --> O
    M --> P(["result feeds the NEXT Corner_Case call as past_cube"])
    O --> P
```

> `esquivar_cubos_1/2/middle` each call `calculte_angle_section_start_clockwise_chr`
> (or its `..._counterclockwise` counterpart) to get an angle + distance to the
> cube, turn toward it (left for green, right for red -- the passing side is set
> by the rules and does not mirror with the driving direction), advance alongside
> it, then small-turn back straight.
> `esquivar_cubos_2` additionally short-circuits to a plain 1000mm advance
> when no second cube is present or it's the same color as the first.

> `Obstacle_Challenge_Thread` also calls `Slope(front)` once, right after
> the initial button-press reset, but resets the gyro to a hardcoded `0`
> right after rather than to that `slope` value -- the measurement is taken
> but its result currently isn't used.

### Thresholds referenced above

| Constant | Value | Where it acts |
|---|---|---|
| Direction-of-run split | `600 mm` | Right reading above this at start -> clockwise run; left reading above this -> counter-clockwise run. Fixed for the whole attempt. |
| Corner approach | `1100 mm` | First advance in every `Corner_Case`, before reading the cube color. |
| Green-cube advance | `600 mm` (parking) / `400 mm` (not) | Second advance in `Corner_Case` when the corner cube is green. |
| Red-cube advance | `990 mm` | Second advance in `Corner_Case` when the corner cube is red. |
| No-cube advance | `650 mm` | Second advance in `Corner_Case` when no cube is seen at the corner. |
| Corner turn | `86 deg` | Every `Corner_Case`, turning into the next section: right when running clockwise, left when running counter-clockwise. |
| Gyro realign | `Slope(outer wall) +/- 90 deg` | Start of every `Desicion`, squares the robot to the outer side wall (on the left running clockwise, on the right running counter-clockwise) before looking for cubes. |
| Corners per run | `12` (3 laps x 4) | 4th corner of each lap calls `Corner_Case`/`Desicion` with `parking=true`. |
| Cube-1 clearance | `hypotenuse - 400` (normal) / `-100` (parking, red) | `esquivar_cubos_1`'s advance-past-cube distance. |
| Cube-2 clearance | `hypotenuse - 400` (normal) / `-150` (parking, green-cube case) | `esquivar_cubos_2`'s advance-past-cube distance. |

---

#### LiDAR & Perception Processing

Wall and corner detection (`Select_Wall()`) follows this pipeline on each call:

1. **Angular windowing**, a 70°-wide window centered on the requested side (front/right/left/behind), with the innermost ±3° excluded to avoid seam/corner noise.
2. **Chassis filtering**, any return closer than 150 mm is discarded as the robot's own body, not an environmental wall.
3. **Radius Outlier Removal (ROR)**, a point is dropped if it has fewer than 3 neighbors within 300 mm (with 15° of padding outside the window so edge points aren't unfairly penalized).
4. **Segmentation**, the remaining points are split into candidate walls wherever consecutive points jump apart by more than 60 mm (gap-based segmentation), then further split at corners using a recursive max-perpendicular-deviation method (Iterative End-Point Fit) with a 40 mm threshold.
5. **Scoring**, a segment only qualifies as a wall if it has at least 6 points, spans at least 200 mm end-to-end (to reject compact objects/blocks), and has an RMS perpendicular residual under 15 mm against its own best-fit line (computed via Total Least Squares/PCA, since it has no bias toward any orientation).
6. **Per-side tracking**, once a wall is chosen for a side, subsequent frames prefer to keep following that same physical wall (matched within 300 mm position / 20° orientation) rather than re-snapping every frame.

Green/red pillar identification is handled by the camera + Hailo-10H YOLOv8n pipeline described in §3.2, which classifies pillar color directly from the RGB frame. The LiDAR's role is purely geometric: once a pillar is flagged by vision, the LiDAR supplies the precise distance/angle used to compute the avoidance vector.

#### Sensor Fusion & Heading Estimation

Heading is provided primarily by the LEGO SPIKE Prime Hub's built-in gyroscope, read and reset via serial commands (`spike.cpp`). This gyro reading is the robot's main orientation reference throughout a run.

LiDAR data supplements this in specific situations rather than being continuously fused with the gyro. During particular maneuvers, wall-orientation readings from the Oradar LiDAR (`Slope()`, `Correction_For_Triangles_Left/Right`, `Advance_And_Measure_Left/Right_Slope`) are used to correct the robot's position and alignment against the track walls.

It's worth being precise about what this is: it is **not** a formal sensor fusion implementation. There is no complementary filter, Kalman filter (EKF), or other algorithm combining the gyro and LiDAR signals into a single fused heading estimate. The architecture is better described as **gyro-primary heading with situational LiDAR-based positional correction**, the SPIKE gyro drives orientation continuously, and the LiDAR steps in at defined points in the maneuver logic to correct drift or misalignment against a known wall reference.

 #### Trajectory Control & Closed-Loop Steering

 Steering uses a Proportional-Derivative (PD) controller: the P term reacts to the lateral position error, and the D term anticipates the rate of change of that error to damp oscillations, allowing smooth trajectories through both the wall-following and obstacle-avoidance challenges.

Two separate PD loops are tuned for the two control contexts:

| Controller | Kp | Kd |
| :--- | :---: | :---: |
| Camera-based cube following | 150 | 100 |
| Gyroscope-based wall following | 2 | 300000 |

Both gain sets were obtained through trial-and-error tuning on the physical track rather than derived analytically.

#### Avoidance & Navigation Logic

* **Passing Rules:** Green → pass on left | Red → pass on right
* **Underlying logic:** pillar color decisions are handled by `Desicion()`/`Corner_Case()`, and the actual avoidance maneuvers are implemented as `esquivar_cubos_1`/`esquivar_cubos_2`/`esquivar_cubos_middle` and `avoid_cube_start_section`, which use angle/hypotenuse geometry (`calculte_angle_section_start_clockwise[_chr]`, `calculte_angle_section_start_counterclockwise`) to aim the robot's approach at each detected pillar's position.
* **Parallel Parking Maneuver:** The camera detects the magenta parking lot markers (labeled `x-parking`) to locate the parking zone. The robot then uses the LiDAR to position itself at a set distance from the wall, and from there uses a combination of LiDAR and gyroscope readings to execute the parking maneuver itself.
#### State Machine & Safety Systems

 * **Robot States:** The `Obstacle_Challenge_Thread` state machine runs: `Booting` → `WaitingForStart` (waits for LiDAR, GPIO, SPIKE hub, and the Hailo model to be ready, then the start button) → `InitialScan` (reads the side-wall distance to pick a direction) → `ClockwiseRun` or `CounterClockwiseRun` → `ExitParkingLot` → a repeating `CornerCycle` (12 total: 3 laps × 4 corners, with the 4th corner of each lap run in parking mode) → `Idle` once all 12 corners are complete → `Stopped` (reachable from any state via Ctrl+C). The direction is decided once in `InitialScan` and held for the whole attempt; the two directions run the same corner cycle with mirrored turn signs and side-wall references.
* **Safety Systems:** `rasp_gpio.cpp` implements a start button (`Rasp_Gpio_Wait_For_Button`) and a status LED, plus a relay that powers on the SPIKE hub at boot. There is no dedicated hardware emergency-stop button separate from process termination (Ctrl+C), and no automatic sensor-failure fallback is implemented. The gyroscope and LiDAR do serve as the robot's recovery mechanism: at the start of every corner's decision logic, the robot re-squares its gyro heading against the LiDAR-measured side wall (`Slope(left)`, ±90°), correcting any drift accumulated during the previous cube-avoidance maneuver before continuing.
---

## 4. Engineering Process & Design Iterations 

>**Full engineering journal:** [`Engineering_Journal_CSS_WRO2026.pdf`](Engineering_Journal_CSS_WRO2026.pdf)
>
>The summary below is deliberately short. The complete account, design reasoning, tradeoff and risk registers, power and torque budgets, the dated logbook, and photographs of every prototype, is in the journal.

### Prototype Evolution

"The Maker" is the **sixth** distinct vehicle the team has built across two seasons. The break between the two seasons was deliberate: the 2026 car is not an incremental descendant of the 2025 one.

| # | Season | Design | Outcome / reason for the next step |
| :--- | :--- | :--- | :--- |
| v1 | 2025 | Hybrid LEGO Technic chassis | Fast to iterate, but component placement was dictated by the Technic hole grid and the assembly had play at every joint |
| v2 | 2025 | Fully custom 3D-printed chassis, double-Ackermann, AWD | **2nd place nationally.** Left us with three structural problems: barely under the 1.5 kg limit, high centre of gravity, inconsistent steering |
| v3 | 2026 | Clean-sheet redesign, RWD, regular Ackermann, battery and Pi dropped low | All three problems were *layout* problems, so the frame was restarted rather than retrofitted |
| v4 | 2026 | Packaging refinement | Component placement tightened around the new layout |
| v5 | 2026 | Mounting revision | Serviceability fixes, including the LiDAR mount fix described below |
| v6 | 2026 | **Final** | The vehicle documented in this README |

Within 2026 the progress was incremental, no iteration after v3 changed the concept. See §2.5 of the journal for the full "we chose X instead of Y" reasoning behind each step.

<table style="width:100%">

<tr>
<td colspan="2" align="center"><b>2025 season</b> — two designs</td>
</tr>

<tr>
<td align="center" width="50%">
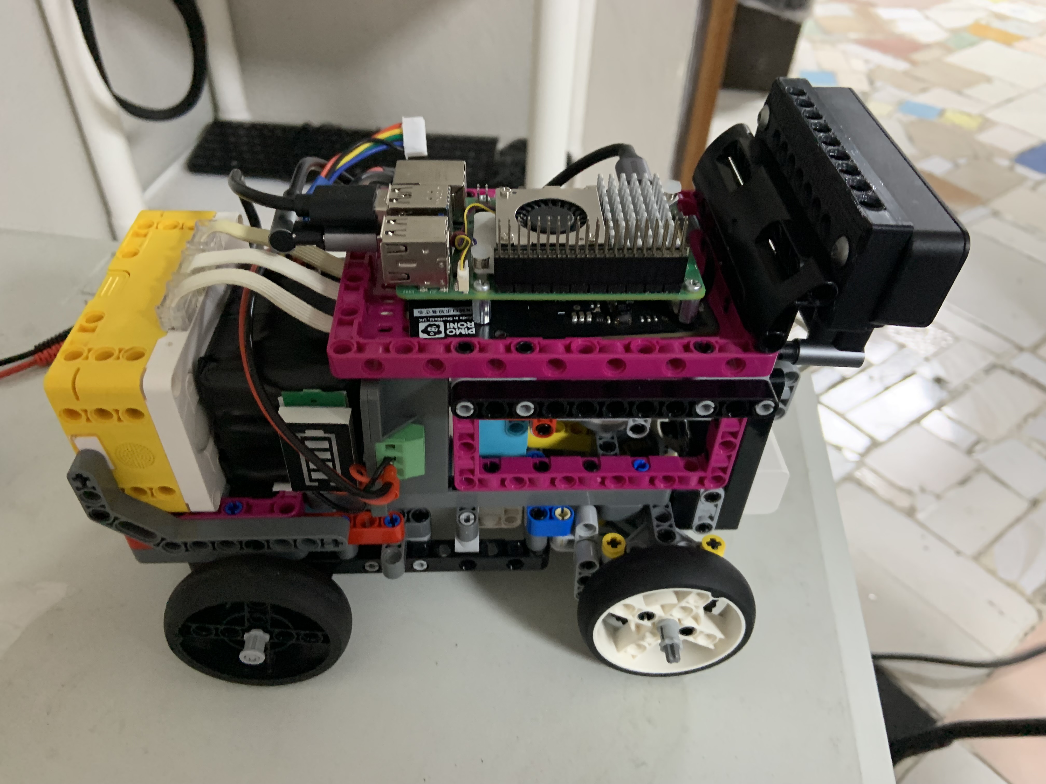
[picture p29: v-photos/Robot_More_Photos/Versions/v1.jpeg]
<br>
<b>v1</b> — Hybrid LEGO Technic chassis<br>
<em>Regional competition (Querétaro). Fast to iterate, but component placement was dictated by the Technic hole grid and the assembly had play at every beam connection.</em>
</td>
<td align="center" width="50%">
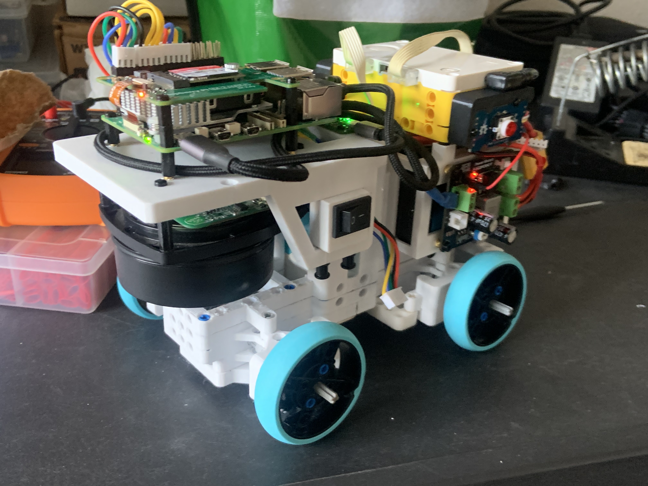
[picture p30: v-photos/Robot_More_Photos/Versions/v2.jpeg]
<br>
<b>v2</b> — Fully custom 3D-printed chassis<br>
<em>National competition, <b>2nd place nationally</b>. Double-Ackermann steering, AWD, RPLidar S2L. Left us with three structural problems: barely under 1.5 kg, high centre of gravity, inconsistent steering.</em>
</td>
</tr>

<tr>
<td colspan="2" align="center"><b>2026 season</b> — clean-sheet redesign, then four iterations</td>
</tr>

<tr>
<td colspan="2" align="center">
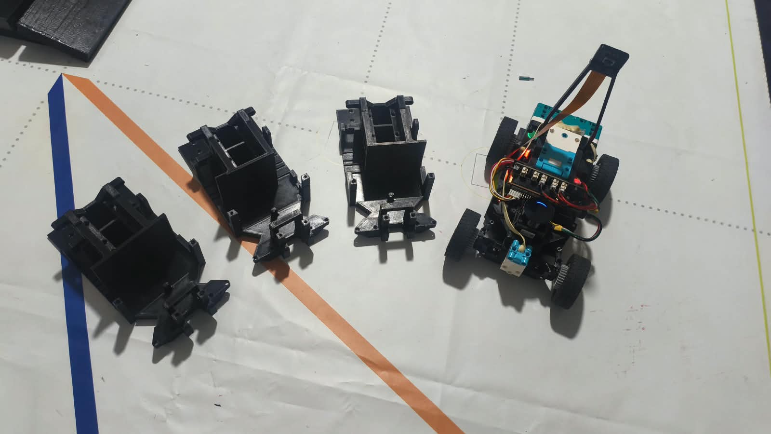
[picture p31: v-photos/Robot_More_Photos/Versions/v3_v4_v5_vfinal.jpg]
<br>
<b>v3, v4, v5</b> (bare printed frames) and <b>v6</b> (assembled, right)<br>
<em>The progression is visible in the frame itself: material removed, mounting features consolidated, and the central bay opened up to drop the electronics lower.</em>
</td>
</tr>

<tr>
<td colspan="2" align="center">
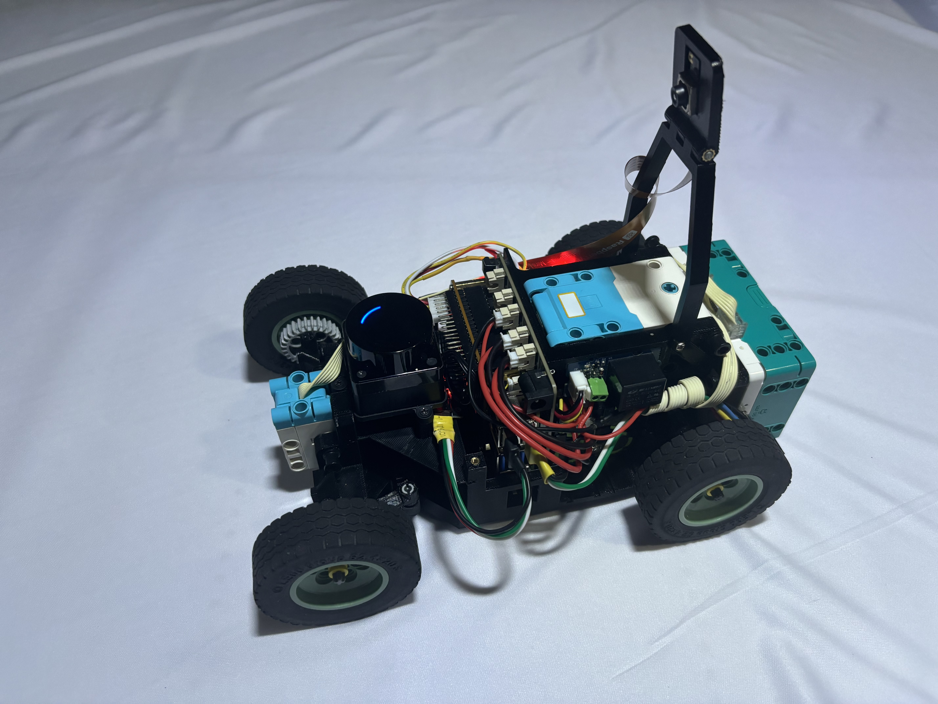
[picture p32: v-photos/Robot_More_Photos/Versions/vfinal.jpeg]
<br>
<b>v6 (final)</b> — <i>"The Maker"</i><br>
<em>RWD, regular Ackermann, Oradar MS200k LiDAR, Raspberry Pi 5 + Hailo-10H. 240 × 160 × 250 mm, 1.006 kg.</em>
</td>
</tr>

</table>

### Key Challenges & Solutions

* **The LiDAR could not see the walls.** After the compact chassis was finished the robot behaved as though blind. The dense repackaging had raised the LiDAR so its scanning plane passed *over* the 100 mm track walls, every wall reading was a miss, not a bad measurement. We revised the central CAD mount to bring the sensor down to ~60–80 mm while keeping the rear field of view clear. Sensor placement is now treated as a constraint set by the field, checked *before* a chassis is printed.
* **Brownouts under hard acceleration.** The Pi 5 and Hailo accelerator caused abrupt shutdowns during acceleration, with the pack still charged. The traction motor's current spike was sagging the rail through the high internal resistance of generic 18650 cells. Fixed with Panasonic NCR18650B cells plus the X1203 board. The lesson: we had specified the pack by capacity (mAh), which is the wrong criterion for a load with sharp transients.
* **Python could not keep up.** With a higher-rate camera and LiDAR attached, the 2025 Python control loop consumed data slower than the sensors produced it, so the robot acted on stale readings. We rewrote acquisition and control in C/C++, a rewrite rather than an optimisation, because the ceiling was the runtime itself, not any single slow function. The loop now runs at **> 50 Hz**.

---

## 5. Construction Guide 

Visit [Assembly instructions](other/Assembly_photos/Assembly_Process_EN.md) for all the details.

## 6. Bill of Materials (BOM) 

| Component | Quantity | Unit Cost (MXN) | Total per Component (MXN) |
| --- | --- | --- | --- |
| [LEGO SPIKE Prime Large Angular Motor (Part 45602)](https://store.edacom.mx/products/spike-motor-angular-grande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) | 1 | $1,737.85 | $1,737.85 |
| [LEGO SPIKE Prime Small Angular Motor (Part 45607)](https://store.edacom.mx/products/spike-motor-angular-pequeno) | 1 | $1,643.96 | $1,643.96 |
| [LEGO Technic Large Hub (Part 45601)](https://www.toytag.com/en-us/products/lego-technic-45601-large-hub-for-spike-prime) | 1 | $10,775.82 | $10,775.82 |
| [4-Pack: LEGO Tires 62.4 x 20 S (32019) & Rims (86652)](https://www.amazon.com.mx/LEGO-Tire-86652-32019-75999/dp/B01CODUYCE) | 1 | $2,079.07 | $2,079.07 |
| [Geekworm X1203 5.1V 5A UPS Shield for Raspberry Pi 5 Series](https://geekworm.com/products/x1203) | 1 | $760.05 | $760.05 |
| [Raspberry Pi 5 (16GB RAM)](https://www.330ohms.com/shop/raspberry-pi-raspberry-pi-5-2/rp-01113-raspberry-pi-5-16gb-1501) | 1 | $7,329.99 | $7,329.99 |
| [Raspberry Pi Camera Module 3 Wide](https://www.330ohms.com/shop/raspberry-pi-raspberry-pi-zero-9/rp-00874-raspberry-pi-camara-3-wide-1326) | 1 | $949.99 | $949.99 |
| [Grove Relay Module](https://www.geekfactory.mx/producto/relevador-grove/) | 1 | $48.00 | $48.00 |
| [Grove Red LED Button Module](https://www.330ohms.com/shop/sd-20069-boton-con-led-rojo-grove-361) | 1 | $16.19 | $16.19 |
| [Raspberry Pi AI HAT+ 40 TOPS (Hailo-10H)](https://www.330ohms.com/shop/raspberrypi-ai-hat2-40tops-1612) | 1 | $5,002.00 | $5,002.00 |
| [Orbbec Oradar MS200k LiDAR](https://tecnodrive.es/products/lidar-ms200k) | 1 | $1,796.21 | $1,796.21 |
| [Panasonic NCR18650B 3400mAh 18650 Li-ion Battery](https://www.mercadolibre.com.mx/ncr18650b-bateria-panasonic-18650-3400mah/up/MLMU723197120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) | 4 | $219.90 | $879.60 |
| **Total (MXN)** |  |  | **$33,018.73** |

> **Disclaimer:** Conversion rates obtained from Google and applied when necessary: 1 United States Dollar equals 16.89 Mexican Peso (Sep 6, 8:28 PM UTC · From Morningstar); 1 Euro equals 19.62 Mexican Peso (Sep 6, 8:32 PM UTC). All prices were retrieved from the links on Sep 6, 2026.

---

### Conversion Notes

* **LEGO Technic Large Hub (45601):** $638.00 USD × 16.89 MXN = **$10,775.82 MXN**
* **Geekworm X1203 UPS Shield:** $45.00 USD × 16.89 MXN = **$760.05 MXN**
* **Orbbec Oradar MS200k LiDAR:** €91,55 EUR × 19.62 MXN = **$1,796.21 MXN**
* **Panasonic NCR18650B Batteries:** $219.90 MXN × 4 units = **$879.60 MXN**

---

## 7. Repository Structure 

```text
.
├── models/                               # CAD designs and 3D vehicle models
│   └── cad/                              # Computer-Aided Design files
│       ├── Final_assembly/               # Current vehicle chassis CAD assembly
│       ├── Iterations/                   # Prototype iterations and legacy CAD files
│       └── Stl/                          # STL CAD Files
├── other/                                # Supporting materials and external software
│   ├── additionalMedia/                  # Extra media assets for documentation
│   │   ├── Others/                       # Miscellaneous diagrams and graphic assets
│   │   └── Videos/                       # Short testing clips and component videos
│   ├── Assembly_photos/                  # Pictures for construction guide
│   ├── dataset/                          # Computer vision dataset for model training
│   │   ├── images/                       # Raw/annotated training images
│   │   └── labels/                       # Bounding box labels (YOLO format)
│   ├── datasheets/                       # Hardware datasheets for sensors and motors
│   ├── software_26topsRaspHAT/           # Raspberry Pi & Hailo AI HAT setup/tools
│   ├── Training_model_and_results/       # Model training scripts and evaluation logs
│   │   └── weights/                      # Model weights (.pt, .onnx, .hef)
│   └── WRO-2026-FE_GeneralRules.pdf      # WRO official competition rules
├── schemes/                              # Electrical documentation & schematics
│   └── hardware/                         # Circuit designs and wiring diagrams
│       └── pcb/                          # Custom PCB schematics and board layouts
│       └── wiringSchematics.jpeg         # System wiring diagram/schematics
├── src/                                  # Main C++ autonomous driving software
│   ├── config/                           # System YAML parameters and config files (Hailo)
│   ├── cpp/                              # Core driving, perception, and control logic
│   ├── HailoModels/                      # Pre-compiled models for Hailo AI accelerator
│   ├── ondevice/                         # Onboard sensor drivers and SDKs
│   │   ├── oradar_sdk/                   # ORadar LiDAR SDK
│   │   └── rplidar_sdk/                  # RPLiDAR SDK
│   └── tools/                            # Utility test scripts and helper binaries (Hailo)
├── t-photos/                             # Team photos (members & coaches)
├── v-photos/                             # Required 6-view vehicle photos
│   └── Robot_More_Photos/                # High-resolution gallery & field testing shots
├── video/                                # Open and Obstacle Challenges YouTube video links
├── .gitignore                            # .gitignore
├── Engineering_Journal_CSS_WRO2026.pdf   # Engineering Journal PDF
├── LICENSE                               # MIT LICENSE file
├── SERVICES_README.md                    # Explanation for setting up daemon services
└── README.md                             # Main project documentation
```

## 8. Setup & Execution Instructions 

This repository builds **two separate programs**: `object_detection` (Obstacle Challenge, camera + Hailo-10H + LiDAR) and a second binary under `src/ondevice/` (Open Challenge, LiDAR + SPIKE hub only, no camera/Hailo). Steps 8.1–8.3 are shared setup; 8.4 and 8.5 cover each program's build/run.

>*More detailed instructions in:*[`src\README.md`](src/README.md)

### 8.1 Prerequisites (OS & hardware stack)

1. **Flash the OS.** Raspberry Pi OS 64-bit (Bookworm or newer) on the Pi 5, via Raspberry Pi Imager. Enable SSH/serial as needed.
2. **Install the Hailo-10H stack** (required for the Obstacle Challenge only). Follow Hailo's Raspberry Pi setup for the AI HAT/M.2 Hailo-10H accelerator: install the `hailo-all` (or Hailo-10H specific) apt packages / PCIe driver + firmware + `HailoRT` runtime + `hailortcli`, then reboot and confirm the device is detected:
```bash
   hailortcli fw-control identify
```
   The installed HailoRT version must match (or be compatible with) the Hailo Dataflow Compiler version used to produce the `.hef` files, for the Hailo-10H specifically, both must be **v5.x** (Hailo-8/8L use a different, incompatible v3.x/v4.x pairing). Mismatched versions are a common cause of a `.hef` that "compiles fine" but fails to load on the Pi.
3. **Install build dependencies:**
```bash
   sudo apt update
   sudo apt install -y build-essential cmake git libopencv-dev libgpiod-dev pkg-config
```

### 8.2 Clone the repository

```bash
git clone --recurse-submodules https://github.com/alex309-duarte/WRO_Future_Engineers_Queretaro_CSS.git
# or, if already cloned:
git submodule update --init --recursive
```
The `--recurse-submodules` step is required, `yaml-cpp` and `curl` under `src/cpp/external/` are vendored as submodules.

### 8.3 Wire up the hardware

- **SPIKE Prime hub:** USB cable, appears as `/dev/ttyACM0` at 115200 baud. 
- **Orbbec Oradar MS200k LiDAR:** USB-serial, `/dev/ttyUSB0` at 230400 baud.
- **GPIO** (BCM numbering): start button on GPIO4, status LED on GPIO3, SPIKE power relay on GPIO2.

*To verify connection with SPIKE Prime HUB, run:*
```bash
   screen /dev/ttyACM0 115200
```
### 8.4 Build & run, Obstacle Challenge (`object_detection`)

1. **Place the model.** Put a compiled `.hef` (see §8.6 to produce your own) under `src/HailoModels/`, or let `resources_manager` resolve/download it per `src/config/resources_config.yaml`.
2. **Set the visualization config path.** `main()` falls back to a hardcoded path that won't exist on a fresh Pi, so export the real one first:
```bash
   export WRO_VISUALIZATION_CONFIG=/absolute/path/to/src/cpp/object_detection_original_h10/visualization_config.yaml
```
3. **Build:**
```bash
   cd src/cpp/object_detection_original_h10/build/h10_original
   make
```
4. **Run** (competition mode, no display):
```bash
   sudo ./object_detection --net /path/to/roboflow_yolov8n_wro_h10.hef --input rpi --no-display
```
   **Run with display** (for debugging/calibration on-track):
```bash
   sudo ./object_detection --net /path/to/roboflow_yolov8n_wro_h10.hef --input rpi
```

### 8.5 Build & run, Open Challenge (`src/ondevice/`)

This binary is built via its own `Makefile` (not CMake) and must be built with the Oradar driver explicitly selected, plain `make` defaults to last year's RPLidar S2L driver, which this year's hardware doesn't use:

```bash
cd src/ondevice
make LIDAR=oradar
make
sudo ./my_lidar_app
```

### 8.6 Calibration steps before first run

- **Gyro:** zeroed automatically at the start of every run (`Reset gyro to 0°`), no manual calibration step needed here.
- **LiDAR mount offset:** `ORADAR_ANGLE_OFFSET` is set to 270°, empirically confirmed for this chassis's LiDAR mounting orientation, only needs re-checking if the LiDAR's physical mounting angle changes.
- **Ackermann steering angle:** fixed at 45.44° in hardware (§3.1), no software calibration needed.

### 8.7 (Optional) Producing your own `.hef` model from scratch

Only needed if retraining the vision model rather than using the one already checked into `src/HailoModels/`.

1. **Get the labeled dataset**:
```bash
   git clone https://github.com/alex309-duarte/WRO_Future_Engineers_Queretaro_CSS.git
```
> Dataset in [`other\dataset`](other/dataset)\
> Training model and results in [`other\Training_model_and_results`](other/Training_model_and_results)

2. **Train the YOLOv8n model** via Google Colab, using [Luxonis's training notebook](https://colab.research.google.com/github/luxonis/depthai-ml-training/blob/master/colab-notebooks/YoloV8_training.ipynb). This project's model was trained with `model=yolov8n.pt`, `epochs=100`, `batch=16`, `imgsz=320`.
3. **Export to `.hef`**, on a laptop/desktop (not the Pi), the recommended one-command path via Ultralytics:
```bash
   pip install ultralytics
   pip install /path/to/hailo_dataflow_compiler-<version>-<pyver>-linux_x86_64.whl
```
```python
   from ultralytics import YOLO
   model = YOLO("best.pt")
   model.export(format="hailo", name="hailo10h", imgsz=320, data="data.yaml")
```
   Requires Hailo Dataflow Compiler **v5.x** (Hailo Developer Zone) for the Hailo-10H.
4. **Deploy:** copy the resulting `.hef` onto the Pi, into `src/HailoModels/`, and pass it via `--net` in §8.4 step 4.

## 9. Driving Videos 

[***Also on  `video\video.md`***](video/video.md)

### Open Challenge
*(Click on preview to visit YouTube Video)*

Open Challenge (https://www.youtube.com/shorts/gWYS8fVQXW0)

### Obstacle Challenge
*(Click on preview to visit YouTube Video)*

Obstacle Challenge (https://www.youtube.com/shorts/b2bn9Eo9FxU)

---

## 10. Resources 

### About WRO
- [WRO Official Site](https://wro-association.org/)
- [Future Engineers Rules](other/WRO-2026-FE_GeneralRules.pdf)

### GitHub Repositories
- [2026 Repository (WRO_Future_Engineers_Queretaro_CSS)](https://github.com/alex309-duarte/WRO_Future_Engineers_Queretaro_CSS)
- [2025 Repository (WRO_2025_SSbots)](https://github.com/JRavenelco/WRO_2025_SSbots)

### Datasheets
- [Orbbec Oradar MS200k LiDAR](other/datasheets/MS200k-dToF-2D-LiDARSR-User-Manual-A2-1.pdf)
- [Raspberry Pi 5 (16GB RAM)](other/datasheets/RP-008348-DS-6-raspberry-pi-5-product-brief.pdf)
- [Raspberry Pi AI HAT+ 40 TOPS (Hailo-10H)](other/datasheets/RP-009655-MM-6-raspberry-pi-ai-hat-plus-2-product-brief.pdf)
- [Geekworm X1203 5.1V 5A UPS Shield for Raspberry Pi 5 Series](https://wiki.geekworm.com/X1203)
- [LEGO SPIKE Prime Large Angular Motor (Part 45602)](other/datasheets/techspecs_techniclargeangularmotor-1b79e2f4fbb292aaf40c97fec0c31fff.pdf)
- [LEGO SPIKE Prime Small Angular Motor (Part 45607)](other/datasheets/LE_SPIKE_Essential_Tech_fact_sheet_Small_Angular_Motor_45607_2HY21_Digital.pdf)
- [LEGO Technic Large Hub (Part 45601)](other/datasheets/techspecs_techniclargehub.pdf)

---

## 11. License 

Released under the [MIT License](LICENSE).

```text
MIT License

Copyright (c) 2026 CSS (Christian Gael Centeno Velez, Sebastián Esquivel Mondragón)

Permission is hereby granted, free of charge, to any person obtaining a copy
of this software and associated documentation files (the "Software"), to deal
in the Software without restriction, including without limitation the rights
to use, copy, modify, merge, publish, distribute, sublicense, and/or sell
copies of the Software, and to permit persons to whom the Software is
furnished to do so, subject to the following conditions:

The above copyright notice and this permission notice shall be included in all
copies or substantial portions of the Software.

THE SOFTWARE IS PROVIDED "AS IS", WITHOUT WARRANTY OF ANY KIND, EXPRESS OR
IMPLIED, INCLUDING BUT NOT LIMITED TO THE WARRANTIES OF MERCHANTABILITY,
FITNESS FOR A PARTICULAR PURPOSE AND NONINFRINGEMENT. IN NO EVENT SHALL THE
AUTHORS OR COPYRIGHT HOLDERS BE LIABLE FOR ANY CLAIM, DAMAGES OR OTHER
LIABILITY, WHETHER IN AN ACTION OF CONTRACT, TORT OR OTHERWISE, ARISING FROM,
OUT OF OR IN CONNECTION WITH THE SOFTWARE OR THE USE OR OTHER DEALINGS IN THE
SOFTWARE.
```

---

> *Document maintained by CSS | Last updated: September 2026*

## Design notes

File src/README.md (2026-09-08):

# object_detection_original_h10

Camera, lidar  and navigation app for the WRO Future Engineers robot, running on a
Raspberry Pi 5 with a Hailo-10H AI accelerator. It runs a Hailo inference
pipeline (traffic-light / cube detection from the camera) alongside an
Oradar MS200 lidar-based wall-following and cube-avoidance state machine that
drives the robot using a LEGO SPIKE Prime hub for robot movements and gyroscope.

We chose rapberry pi 5 because it has a PCI port which is the only one compatible with AI HAT for raspberry in any of its versions. For the AI HAT, the Raspberry Pi AI HAT+ 2 (40 TOPS + 8GB RAM) offers the best performance and keeps the current consumption low. A YOLO model 8 NANO was trained using the dataset images included in this repository. In the following secctions is described how to generate the ONNX model and from that model generate the HEF File which is the model used by the raspberry Pi AI HAT+ 2.

## 1. Module table

Files under `src/cpp/object_detection_original_h10/`:

| File | Module | Description |
|---|---|---|
| `object_detection.cpp` | Main application | Parses CLI args, loads the Hailo model (`HailoInfer`), wires the preprocess -> inference -> postprocess pipeline threads, and spawns `Obstacle_Challenge_Thread`. `postprocess_callback` draws detections and also runs the lidar wall-segmentation/orientation logic (`Select_Wall`, `Fit_Line_Orientation`, `Slope`, `Distance_To_Wall`) used for wall detection. The bulk of the file implements the Obstacle Challenge state machine: cube-color decision logic (`Desicion`, `Corner_Case`), cube avoidance maneuvers (`esquivar_cubos_1/2/middle`, `avoid_cube_start_section`), and the angle/hypotenuse geometry used to aim at each cube (`calculte_angle_section_start_clockwise[_chr]`, `calculte_angle_section_start_counterclockwise`). |
| `Oradar_S2L.h` / `Oradar_S2L.cpp` | Oradar MS200 lidar driver | Owns the connection to the Oradar lidar (`Oradar_S2L_Init_Lidar`, background `Oradar_S2L_Lidar_Writer_Thread` that fills a 360-slot distance buffer), exposes the buffer (`Oradar_S2L_Get_Buffer`), degree/radian conversions, and a set of wall-relative navigation primitives (`Advance_And_Detect_Side`, `Advance_Until_Left/Right_Gap`, `Advance_And_Measure_Left/Right_Slope`, `Correction_For_Triangles_Left/Right`, `Slope`/`Slope2` least-squares wall-angle fits, `Reconcile_Readings`, `Average`). `RP_TO_ORADAR_IDX` translates the logical `LidarSide` angle (`FRONT`/`RIGHT`/`BACK`/`LEFT`, defined in `common_var.h`) into the Oradar's raw buffer index. |
| `spike.h` / `spike.cpp` | SPIKE Prime driver | Serial link (over USB, `/dev/ttyACM0`) to the LEGO SPIKE Prime hub. Sends python source lines as serial commands (`Spike_Send_Serial_Data`)(C-python is the progrmming lenguage of the SPIKE Hub) to define on-hub motor-control routines at boot (`Spike_Initialize_Libraries`), then triggers them for turns, straight advances, centering, gyro reset/read, etc. |
| `rasp_gpio.h` / `rasp_gpio.cpp` | Raspberry Pi GPIO | Uses `libgpiod` to read the start button, drive the status LED, and pulse the relay that powers on the SPIKE hub (`Rasp_Gpio_Init`, `Rasp_Gpio_Wait_For_Button`, `Rasp_Gpio_Power_On_Spike`, `Rasp_Gpio_Clean`). |
| `common_var.h` | Shared constants | `direction`, `Color_traffic_light`, `Cube_number[_chr]`, `Brake_type`, and `LidarSide` enums plus the global `terminating_main` flag shared across the lidar/Spike/GPIO/main modules. |
| `utils/utils.hpp` / `utils/utils.cpp` | Hailo postprocessing helpers | Bounding-box drawing, NMS output parsing (`parse_nms_data`) into `NamedBbox`, and COCO class name/color lookup helpers used by `postprocess_callback`. |

Notes:
This code contain in cpp folder is a copy from the Hailo apps examples to runs a simple object detection algorithm using their own hef file or a costum one. from that example is where we start adding the rest of the source files and change the make files to be able to compile from the repository folder. The repository can be placed in the home folder fromthe raspberry or another folder, in the following section a description on how to install the HAILO aplication is described. Other examples remain as part of the original repository from hailo apps. you need to look in the following path 'src/cpp/object_detection_original_h10/' to found the files that contains all the code. To compile it you need to navigate from that path to 'build/h10_original' executing make. After the make command it will generate the executable called "object_detection"

**External dependencies used but not in this folder** (wired in via `CMakeLists.txt`, code lives in `src/cpp/common/`): `toolbox.hpp/.cpp` and `hailo_infer.hpp/.cpp` (shared Hailo pipeline plumbing: arg parsing, preprocess/inference/postprocess thread runners) and `resources_manager.hpp/.cpp` (resolves a `--net` model name/path to a local `.hef`, downloading it if needed per `config/resources_config.yaml`). The Oradar SDK (`oradar_sdk/`) and the `yaml-cpp`/`curl` submodules (`../external/`) are vendored source trees pulled in by `CMakeLists.txt` via `add_subdirectory`.

## 2. Running this code on another Raspberry Pi 5 + Hailo-10H

1. **Flash the OS.** Raspberry Pi OS 64-bit (Bookworm or newer) on the Pi 5, via Raspberry Pi Imager. Enable SSH/serial as needed.
2. **Install the Hailo-10H stack.** 
IMPORTANT: before instlling make sure you have at least the Raspberry Pi AI HAT+ 2 (40 TOPS + 8GB RAM) connected to the raspberry pi 5, if not the compilation will fail.
Follow Hailo's Raspberry Pi setup for the AI HAT/M.2 Hailo-10H accelerator: install the `hailo-all` (or Hailo-10H specific) apt packages / PCIe driver + firmware + `HailoRT` runtime + `hailortcli` from Hailo's Raspberry Pi apt repo, then reboot and confirm the device is detected:
   ```bash
   hailortcli fw-control identify
   ```
   The HailoRT version installed here must match (or be compatible with) the Hailo Dataflow Compiler version used to produce the `.hef` files (see part 4).
3. **Install build dependencies.**
   ```bash
   sudo apt update
   sudo apt install -y build-essential cmake git libopencv-dev libgpiod-dev pkg-config
   ```
4. **Clone the repo with submodules** (needed for `yaml-cpp`/`curl` under `src/cpp/external/`):
   ```bash
   git clone --recurse-submodules https://github.com/alex309-duarte/WRO_Future_Engineers_Queretaro_CSS.git
   # or, if already cloned:
   git submodule update --init --recursive
   ```
5. **Place the `.hef` model(s).** Put the compiled model (see part 4) under `src/HailoModels/`, or let `resources_manager` resolve/download it per `src/config/resources_config.yaml` (`hailo10h` architecture entries).
6. **Check the hardcoded visualization-config fallback path.** `main()` in `object_detection.cpp` falls back to a hardcoded path (`/home/maker/WRO_Hailo10H_Compatible/software/cpp/object_detection_original_h10/visualization_config.yaml`) if the `WRO_VISUALIZATION_CONFIG` env var isn't set. On a fresh Pi that path won't exist -- either export the env var, or update the fallback:
   ```bash
   export WRO_VISUALIZATION_CONFIG=/absolute/path/to/src/cpp/object_detection_original_h10/visualization_config.yaml
   ```
7. **Build.**
   ```bash
   cd src/cpp/object_detection_original_h10/build/h10_original
   make
   ```
8. **Wire up the hardware:**
   - SPIKE Prime hub: USB cable, appears as `/dev/ttyACM0` (see `spike.cpp`).
   - Oradar MS200 lidar: USB-serial, `/dev/ttyUSB0` at 230400 baud (see `Oradar_S2L.cpp`).
   - GPIO (BCM numbering, see `rasp_gpio.h`): button on GPIO4, status LED on GPIO3, SPIKE power relay on GPIO2.
9. **Run.**
   ```bash
   ./object_detection --net <model_name_or_path.hef> [other args parsed by toolbox.cpp]
   ```

## 3. From dataset to a working `.hef` (beginner walkthrough)

This section is written for someone doing this for the first time. A `.hef` file
is just "a neural network, packaged in the one format the Hailo chip understands."
You can't hand the Hailo chip a normal file straight out of training (an `.onnx`
or `.pt` file) -- you first have to *compile* it, similarly to how you compile
C++ source into a binary the CPU can run. That compiling step is what most of
this section is about.

There are two separate computers involved, and it's easy to mix them up:

- **Your laptop/desktop (x86_64, Windows/Linux/Mac)** -- where you train the
  model and compile it into a `.hef`. This needs a lot of RAM and, for
  reasonable training speed, a GPU (Google Colab gives you one for free).
- **The Raspberry Pi 5** -- where the finished `.hef` actually *runs*, inside
  this repo's `object_detection` program. The Pi never trains or compiles
  anything; it only runs the already-compiled file.

### 3.1 Get the labeled dataset

The images and annotations used to train the traffic-light/cube detector live:

**Get the labeled dataset**:
```bash
   git clone https://github.com/alex309-duarte/WRO_Future_Engineers_Queretaro_CSS.git
```
> Dataset in [`other\dataset`](other/dataset)\
> Training model and results in [`other\Training_model_and_results`](other/Training_model_and_results)

Inside it, `other\dataset` has:

- `images/` -- the photos.
- `labels/` -- one `.txt` file per image, in YOLO format (one line per object:
  `class_id x_center y_center width height`, all normalized 0-1).
- `classes.txt` -- the list of class names, in the same order as the
  `class_id` numbers used in `labels/`.

This is a *raw* Label Studio export: everything is in one folder, not yet
split into a training set and a validation set, and there's no `data.yaml`
(the small config file that tells YOLO where the images/labels live and what
the classes are called). You'll create both of those in the next step.

### 3.2 Train the YOLOv8n model

This project's own README documents training via Google Colab, using
Luxonis's ready-made notebook:
[YoloV8_training.ipynb](https://colab.research.google.com/github/luxonis/depthai-ml-training/blob/master/colab-notebooks/YoloV8_training.ipynb).
Colab gives you a free cloud GPU in the browser -- no local install needed for
this step.

1. Open the notebook link above and make a copy to your own Google Drive
   (`File -> Save a copy in Drive`) so you can edit and re-run it.
2. Upload the `DataSet_labelStudio` folder (or `images/` + `labels/` +
   `classes.txt`) to your Google Drive, and mount Drive in the notebook so it
   can read those files.
3. Follow the notebook's own steps to split the images into `train/` and
   `val/` subsets and generate a `data.yaml` pointing at them, using the
   class names from `classes.txt`.
4. Train. The settings this project's own trained model used (visible in
   `model_training/Training_model_and_results/args.yaml` in the dataset
   repo) were:
   - model: `yolov8n.pt` (the smallest/fastest YOLOv8 variant -- what you
     want on a small on-device accelerator like the Hailo-10H)
   - `epochs=100`, `batch=16`, `imgsz=320`
   - In the notebook (or a plain terminal with `pip install ultralytics`),
     this is the equivalent of:
     ```bash
     yolo detect train model=yolov8n.pt data=data.yaml epochs=100 batch=16 imgsz=320
     ```
   Training can take anywhere from tens of minutes to a few hours depending
   on dataset size and Colab's GPU allocation for that session -- this is
   expected, just let it run.
5. When it finishes, your trained weights are at
   `runs/detect/train/weights/best.pt`. Download that file -- it's what the
   next step converts.

### 3.3 Turn `best.pt` into a `.hef`

There are two ways to do this. **Use option A unless you have a specific
reason not to** -- it's one command instead of a whole toolchain install.

#### Option A (recommended): one-command export via Ultralytics

Recent versions of the `ultralytics` Python package can export straight to a
Hailo `.hef`, handling the ONNX conversion and the Hailo compiler internally.
On your laptop/desktop (not the Pi):

```bash
pip install ultralytics
pip install /path/to/hailo_dataflow_compiler-<version>-<pyver>-linux_x86_64.whl
```

(You still need the Hailo Dataflow Compiler `.whl` -- see the version note
below for which one to download from the
[Hailo Developer Zone](https://hailo.ai/developer-zone/) (free account
required).)

```python
from ultralytics import YOLO

model = YOLO("best.pt")
model.export(format="hailo", name="hailo10h", imgsz=320, data="data.yaml")
```

This produces a `.hef` file targeting the Hailo-10H directly.

#### Option B (manual/classic): `hailomz` step-by-step

This is the flow from Cytron's
[Raspberry Pi AI Kit: ONNX to HEF Conversion](https://www.cytron.io/tutorial/raspberry-pi-ai-kit-onnx-to-hef-conversion)
guide (written for the older Hailo-8L kit) -- useful if you want more control
over each step, or option A isn't available for your `ultralytics` version.
**Do this on a separate x86_64 Linux machine, not the Pi**: the Dataflow
Compiler needs real CPU/RAM (Hailo recommends >=32 GB RAM for the
quantization/calibration step) and doesn't run on the Pi's ARM CPU.

1. **Install host prerequisites:**
   ```bash
   sudo apt update
   sudo apt install -y python3-pip python3.10-venv build-essential graphviz graphviz-dev
   pip install pygraphviz
   ```
2. **Create and activate a virtual environment** (an isolated Python install
   so this doesn't clash with other Python projects on your machine):
   ```bash
   python3.10 -m venv hailo_dfc_env
   source hailo_dfc_env/bin/activate
   ```
3. **Install the Hailo Dataflow Compiler** (see the version note below for
   which one), then sanity-check it installed correctly:
   ```bash
   pip install hailo_dataflow_compiler-<version>-<pyver>-linux_x86_64.whl
   hailo -h
   ```
4. **Get the Hailo Model Zoo** (a collection of ready model configs/scripts
   that `hailomz` uses):
   ```bash
   git clone https://github.com/hailo-ai/hailo_model_zoo.git
   cd hailo_model_zoo
   pip install -e .
   ```
5. **Export `best.pt` to ONNX first** (`hailomz` wants ONNX in, not `.pt`;
   `opset=11` specifically, or the Hailo compiler will fail to read the file):
   ```bash
   yolo export model=best.pt format=onnx imgsz=320 opset=11
   ```
6. **Compile the ONNX into a `.hef`, targeting Hailo-10H** (`--calib-path`
   should point at a folder of representative images -- e.g. a subset of your
   own `val/` images -- the compiler uses these to calibrate INT8 quantization
   accuracy; `--classes` is how many object classes your model detects):
   ```bash
   hailomz compile <model_name> \
     --ckpt=<path/to/best>.onnx \
     --hw-arch hailo10h \
     --calib-path <path/to/calibration/images> \
     --classes <N> \
     --performance
   ```
   This produces `<model_name>.hef` in the working directory.

### 3.4 Dataflow Compiler / HailoRT version compatibility -- read this before installing

The Hailo-8/8L and the Hailo-10H are different chip generations and **use of
different major versions of the toolchain** -- installing the wrong one is
the single most common reason this whole process fails partway through:

| Target chip | Dataflow Compiler (DFC) | HailoRT (runtime, installed on the Pi) |
|---|---|---|
| Hailo-8 / Hailo-8L | v3.x (e.g. 3.28-3.33) | v4.x (e.g. 4.17-4.23) |
| **Hailo-10H / Hailo-15 (this project)** | **v5.x** | **v5.x** |

For this project's hardware, install **DFC v5.x on your training machine**
(the [Hailo Developer Zone](https://hailo.ai/developer-zone/) download page
lets you pick the version) and make sure the **HailoRT you install on the
Raspberry Pi in part 3, step 2 is also v5.x, and as close as possible to the
same version** -- e.g. DFC 5.3.0 pairs with HailoRT 5.3.0. Mismatched major
versions between the compiler and the on-device runtime are a common source
of `.hef` files that fail to load on the Pi even though compilation "succeeded."
If in doubt, check the exact pairing on the Version Compatibility Table page
in the Hailo AI Software Suite documentation.

### 3.5 Deploy

Copy the resulting `.hef` onto the Pi 5, into `src/HailoModels/` (or wherever
`--net`/`resources_config.yaml` expects it), and pass its name/path to
`--net` when running `object_detection` (part 3, step 9).

# How to run

### Run this command to run obstacle challenge with no display
sudo /home/maker/WRO_Future_Engineers_Queretaro_CSS/src/cpp/object_detection_original_h10/build/h10_original/object_detection   --net /home/maker/WRO_Future_Engineers_Queretaro_CSS/src/HailoModels/roboflow_yolov8n_wro_h10.hef   --input rpi --no-display

### Run this command to run obstacle challenge with display
sudo /home/maker/WRO_Future_Engineers_Queretaro_CSS/src/cpp/object_detection_original_h10/build/h10_original/object_detection   --net /home/maker/WRO_Future_Engineers_Queretaro_CSS/src/HailoModels/roboflow_yolov8n_wro_h10.hef   --input rpi

## 5. Obstacle Challenge flow

Two threads run at once (both started from `main()`): the Hailo camera
pipeline keeps the global `traffic_lights` struct (color, x-position, area,
confidence) updated in the background, while `Obstacle_Challenge_Thread`
drives the robot and reads that struct whenever it needs to know what cube
it's currently looking at. The diagrams below are the navigation thread.

### 5.1 High-level states

```mermaid
stateDiagram-v2
    [*] --> Booting
    Booting --> WaitingForStart: lidar + GPIO + Spike + Hailo model ready
    WaitingForStart --> InitialScan: start button pressed
    InitialScan --> ClockwiseRun: right-side reading > 600mm
    InitialScan --> CounterClockwiseStub: left-side reading > 600mm
    ClockwiseRun --> ExitParkingLot: estacionamiento_clockwise()
    ExitParkingLot --> CornerCycle
    CornerCycle --> CornerCycle: x12 total -- 3 laps x 4 corners,\n4th corner of each lap runs with parking=true
    CornerCycle --> Idle: 12 corners complete
    CounterClockwiseStub --> Idle: single 45deg turn only
    Idle --> Stopped: Ctrl+C
    WaitingForStart --> Stopped: Ctrl+C
    InitialScan --> Stopped: Ctrl+C
    CornerCycle --> Stopped: Ctrl+C
    Stopped --> [*]
```

> **CounterClockwiseStub is exactly that today** -- the `else if
> (distancia_izquierda > 600)` branch in `Obstacle_Challenge_Thread` only
> does one 45&deg; turn and falls straight through to `Idle`; the 12-corner
> loop that the clockwise path has was never written for this direction.

### 5.2 One corner cycle (repeats x12)

`Corner_Case` and `Desicion` together are the unit that repeats 12 times.
Drawn once here rather than 12 times over.

```mermaid
flowchart TD
    A(["Corner_Case(past_cube, parking)"]) --> B["Advance to 1100mm from the front wall"]
    B --> C["Read the cube color the camera<br/>currently sees: traffic_lights.light_color"]
    C --> D{"cube color?"}
    D -- green --> E["Advance to 600mm (parking)<br/>or 400mm (not parking)"]
    D -- red --> F["Advance to 990mm"]
    D -- none --> G["Advance to 650mm<br/>set is_middle_case from the PREVIOUS cube's color"]
    E --> H["Turn 86&deg; right, center vehicle, coast"]
    F --> H
    G --> H
    H --> I(["Desicion(cube, is_middle_case, parking)"])
    I --> J["Sleep 1s, then Slope(left)<br/>reset gyro +/-90deg to square up to the side wall"]
    J --> K{"was a cube already<br/>seen right at the corner?"}
    K -- "no (color was none)" --> L{"is_middle_case?"}
    L -- yes --> M["esquivar_cubos_middle(parking)<br/>one cube in the middle of the section"]
    L -- no --> N["esquivar_cubos_1(parking)<br/>avoid the first cube"]
    N --> O["esquivar_cubos_2(result, parking)<br/>look for + avoid a second cube"]
    K -- yes --> O
    M --> P(["result feeds the NEXT Corner_Case call as past_cube"])
    O --> P
```

> `esquivar_cubos_1/2/middle` each call `calculte_angle_section_start_clockwise_chr`
> to get an angle + distance to the cube, turn toward it (left for green,
> right for red), advance alongside it, then small-turn back straight.
> `esquivar_cubos_2` additionally short-circuits to a plain 1000mm advance
> when no second cube is present or it's the same color as the first.

> `Obstacle_Challenge_Thread` also calls `Slope(front)` once, right after
> the initial button-press reset, but resets the gyro to a hardcoded `0`
> right after rather than to that `slope` value -- the measurement is taken
> but its result currently isn't used.

### 5.3 Thresholds referenced above

| Constant | Value | Where it acts |
|---|---|---|
| Direction-of-run split | `600 mm` | Right reading above this at start -> clockwise run; left reading above this -> the counter-clockwise stub. |
| Corner approach | `1100 mm` | First advance in every `Corner_Case`, before reading the cube color. |
| Green-cube advance | `600 mm` (parking) / `400 mm` (not) | Second advance in `Corner_Case` when the corner cube is green. |
| Red-cube advance | `990 mm` | Second advance in `Corner_Case` when the corner cube is red. |
| No-cube advance | `650 mm` | Second advance in `Corner_Case` when no cube is seen at the corner. |
| Corner turn | `86 deg` right | Every `Corner_Case`, turning into the next section. |
| Gyro realign | `Slope(left) +/- 90 deg` | Start of every `Desicion`, squares the robot to the side wall before looking for cubes. |
| Corners per run | `12` (3 laps x 4) | 4th corner of each lap calls `Corner_Case`/`Desicion` with `parking=true`. |
| Cube-1 clearance | `hypotenuse - 400` (normal) / `-100` (parking, red) | `esquivar_cubos_1`'s advance-past-cube distance. |
| Cube-2 clearance | `hypotenuse - 400` (normal) / `-150` (parking, green-cube case) | `esquivar_cubos_2`'s advance-past-cube distance. |

# How to run

### Run this command to run obstacle challenge with no display
sudo /home/maker/WRO_Future_Engineers_Queretaro_CSS/src/cpp/object_detection_original_h10/build/h10_original/object_detection   --net /home/maker/WRO_Future_Engineers_Queretaro_CSS/src/HailoModels/roboflow_yolov8n_wro_h10.hef   --input rpi --no-display

### Run this command to run obstacle challenge with display
sudo /home/maker/WRO_Future_Engineers_Queretaro_CSS/src/cpp/object_detection_original_h10/build/h10_original/object_detection   --net /home/maker/WRO_Future_Engineers_Queretaro_CSS/src/HailoModels/roboflow_yolov8n_wro_h10.hef   --input rpi

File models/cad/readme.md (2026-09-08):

# Models

This directory contains the complete 3D assembly and the individual parts that make up the robot. It also includes the `.stl` files used for 3D printing essential structural components, such as the main chassis and various mounts.

## Design Objectives

The primary objective behind the robot's mechanical design was maximum space optimization. This approach was essential to achieve two critical goals:
* **Center of Gravity:** Lowering the center of gravity as much as possible to ensure maximum stability during high-speed maneuvers on the track.
* **Sensor Placement:** Lowering the LiDAR sensor enough to accurately detect the 10 cm high track walls across a full 360-degree field of view.

### The LiDAR Challenge
Reaching the final design required an extensive testing process, evaluating multiple component layouts. One of the most persistent challenges was the LiDAR positioning. Because the sensor has a built-in pitch angle of 2 degrees, placing it too high caused the laser to overshoot the 10 cm walls at longer distances. 

To resolve this, the internal layout was heavily optimized, successfully lowering the LiDAR to a height where it reliably detects all track boundaries without blind spots.

## Engineering and Kinematics

### Ackermann Steering
The vehicle incorporates Ackermann steering geometry, allowing the robot to navigate turns smoothly without wheel slip or drag. Through this mechanical design, a maximum steering angle of 45.44 degrees was achieved.

### Wheelbase-to-Track Ratio
To guarantee driving stability and reliable cornering, a wheelbase-to-track ratio of 1.34 was implemented. This proportion was intentionally selected to closely mimic the 1.4 ratio commonly used in real-world automotive design, ensuring optimal handling characteristics.

## Maintenance and Accessibility

For competition environments, quick maintenance is crucial. The mechanical design optimizes ergonomics and accessibility:
* **Battery Replacement:** The chassis allows for fast and effortless swapping of the LEGO Spike batteries.
* **Accessible Electronics:** All connectors, wiring, and modules are strategically placed within reach, enabling rapid troubleshooting and repairs between competition rounds.

## Software and Resources

* **CAD Software:** The 3D modeling and assembly were carried out using SolidWorks 2026, chosen due to the team's extensive experience with this software.
* **CAD Libraries:** Platforms like GrabCAD were utilized to source 3D models for standard electronic components, including the Raspberry Pi and Grove modules.
* **Manufacturer Documentation:** External components, such as the Oradar LiDAR, were integrated using official technical documentation and dimensions provided by the manufacturers.

## Contents

* **`Iterations/`**: Contains previous design iterations, early prototypes, and testing models used throughout the development process.
* **`Final_assembly/`**: Contains the final 3D CAD assembly of the robot, representing the definitive competition model.
* **`Stl/`**: Contains the `.stl` files of all the custom components that were physically 3D printed to build the robot.

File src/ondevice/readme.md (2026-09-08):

# On-Device Source Code (`src/ondevice`)

This directory contains the C and C++ source files and header libraries (`.c`, `.cpp`, `.h`) required to run the robot's control logic, sensor data acquisition, and actuation for the First Challenge.

## Directory Overview

* **Source Files (`.c` / `.cpp`):** Implement low-level control algorithms, finite state machine logic, peripheral drivers, and hardware communications.
* **Header Files (`.h`):** Define pin mappings, data structures, function prototypes, and global configuration constants.

## Flowcharts and State Diagrams

For a detailed view of the execution flow and system logic:

1. **Main README:** Refer to the root [`README.md`](../../README.md) for a high-level overview of the software architecture and system design.
2. **Schematics and Diagrams:** Visit the [`/schematics`](../../schematics) directory to access the system flowcharts and state machine diagrams.

## Technical Specifications

* **Programming Languages:** C / C++
* **Target Platform:** On-board embedded platform / RaspberryPi5-Lego Spike Prime
* **Dependencies:** Local header files and platform-specific libraries configured within the source tree.

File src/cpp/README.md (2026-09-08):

# CPP Examples

> ⚠️ **Beta:** The C++ applications are currently in beta. Features and APIs may change.

go to folder "object_detection_original_h10" for obstacle challenge source code.

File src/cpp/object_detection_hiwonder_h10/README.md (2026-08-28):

# Object detection H10 + Hiwonder

Variante nueva del programa
`object_detection_original_h10`. Conserva Hailo10H, cámara, Oradar, detección
YOLO y la lógica de misión, pero sustituye el REPL del LEGO SPIKE por la placa
Hiwonder mediante `hiwonder::Brick` y `spike_compat`.

El original no se modifica. En la Raspberry esta variante vive en:

```text
/home/maker/WRO_Future_Engineers_Queretaro_CSS/software_h10/cpp/object_detection_hiwonder_h10
```

## Seguridad de arranque

Sin `HIWONDER_ARM=1`, el programa sólo inicia cámara, Hailo y LiDAR. No abre el
controlador Hiwonder ni crea el hilo de movimiento. En modo armado valida todos
los parámetros antes de abrir el puerto y, sin mover actuadores, comprueba:

- `MOTOR_EXT` versión 1;
- M1 habilitado y 1320 ticks por vuelta;
- telemetría IMU;
- calibración del bias del giroscopio.

Después arranca el pipeline Hailo y sólo entonces crea la misión. El movimiento
sigue esperando el botón físico GPIO4. El relé GPIO2 del SPIKE no se solicita
ni se pulsa.

## Compilar

```bash
cd ~/WRO_Future_Engineers_Queretaro_CSS/software_h10/cpp/object_detection_hiwonder_h10
cmake -S . -B build/h10_hiwonder -DCMAKE_BUILD_TYPE=Release
cmake --build build/h10_hiwonder -j"$(nproc)"
```

El SDK Oradar se reutiliza de sólo lectura desde el directorio hermano
`object_detection_original_h10/oradar_sdk`.

## Probar percepción sin motores

```bash
./run_hiwonder.sh
```

Equivale al comando original con el mismo modelo y `--input rpi`, pero deja
`HIWONDER_ARM=0`.

## Armar, sólo después de calibrar

```bash
cp hiwonder.env.example hiwonder.env
# Editar y medir todos los campos vacíos.
./run_hiwonder.sh --arm
```

`--arm` habilita la conexión, no inicia el movimiento: todavía hay que pulsar
el botón físico. Si falta un valor, el firmware no es `pos-v4`, no llega IMU o
el puerto es ambiguo, el proceso termina antes de crear la misión.

## Diferencias inevitables respecto al SPIKE

- `Spike_Forward` y `Spike_Follow_Reference` ejecutan un paso de PD por llamada.
- Avance y giros conservan su semántica bloqueante y añaden timeout.
- `Spike_Hold_Motors` se aproxima con parada; M1 no tiene HOLD posicional.
- `Spike_Advance_For_distance` usa diámetro real de rueda y un factor de
  distancia configurable, no la constante de la rueda LEGO.
- Los factores y ganancias del LEGO no se reutilizan automáticamente.

No hace falta volver a flashear: la placa ya fue verificada byte por byte contra
`RosRobotControllerM4-extended-m1-pos-v4.hex`.

## Verificación realizada

En la Raspberry Pi 5 se configuró y compiló la variante completa con GCC 14.2.
Una ejecución desarmada de 10 segundos confirmó cámara RPi, Hailo10H y Oradar
simultáneos, sin abrir Hiwonder, con aproximadamente 29.95 FPS y salida limpia
al recibir `SIGINT`. Una ejecución con `HIWONDER_ARM=1`, sin placa ni
calibración, terminó antes de cargar el modelo y antes de crear el hilo de
misión, como exige la guarda de seguridad.

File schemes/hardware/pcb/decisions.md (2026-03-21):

# Decisions - PCB Phase 2

## Closed baseline decisions
- Control architecture: local MCU + optional external host.
- Baseline MCU: `STM32F103RCT6` or pin-compatible equivalent.
- Battery baseline: `3S Li-ion/LiPo`.
- Active rails: `IN12V`, `VM`, `+5V`, `+3V3`.
- Primary programming/debug: `SWD`.
- Normal host communication: `UART`.
- IMU: `ICM20948`.
- Motor scope: only `Motor 1` is active in this revision.
- Out of active scope: `CAN`, `OLED`, `servo`, `M2`, `M3`, `M4`.

## Phase 2 implementation scope
Active sheets in this revision:
- `power`
- `mcu`
- `debug`
- `usb_uart`
- `imu`
- `motors_4x` implemented as `M1 only`
- `user_io`
- `connectors`

Inactive by scope and not wired in root sheet:
- `can.kicad_sch`
- `oled.kicad_sch`
- `servo.kicad_sch`

## Deviations and rationale
- The sheet file name `motors_4x.kicad_sch` was preserved for continuity, but only `M1` is implemented in this revision.
- `user_io` is kept active only for minimum reset/boot accessibility.
- `usb_uart` remains interface-only in this phase. No USB-UART bridge IC is committed yet.
- Ground domains `GND`, `DGND`, `AGND`, and `VGND` are exposed as explicit design domains. They are not shorted in this phase.
- The PDF reference is treated as topological guidance; this project scope follows the current baseline message when there is a scope conflict.

## IMU interface decision status
Current status: not fully frozen at electrical implementation level.

Phase 2 boundary decision:
- Keep both `IMU_SDA_SDI` and `IMU_SCL_SCLK` names to preserve I2C/SPI optionality.
- Keep `IMU_nCS` and `IMU_AD0_SDO` visible.

Short tradeoff:
- `I2C`: fewer MCU pins, simpler routing, easier shared bus.
- `SPI`: better throughput, lower latency, better for deterministic burst reads.

Provisional recommendation for next phase:
- Prefer `SPI` if high-rate inertial acquisition is required.
- Prefer `I2C` if simplicity and pin economy are prioritized.

## Power decisions intentionally left open
- Final battery connector: `XT30` vs terminal block.
- Exact 5 V buck regulator component.
- Exact 3.3 V regulator/LDO component.
- Real motor peak current and protection sizing.
- Final USB-UART implementation choice.

## Notes for next phase
- Add real MCU symbol and freeze pinout.
- Add real power conversion topology.
- Add motor driver/protection based on current target.
- Freeze IMU bus as `I2C` or `SPI` before selecting passives and pull-ups.

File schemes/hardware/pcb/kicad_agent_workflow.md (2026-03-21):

# KiCad Agent Workflow

## Objetivo
Usar un agente GUI externo para operar KiCad, mientras Cascade prepara instrucciones exactas, archivos y validación ERC.

## Modelo operativo

### Roles
- **Cascade**
  - Decide qué cambiar
  - Edita archivos del proyecto cuando convenga
  - Define el cableado exacto y el símbolo correcto
  - Ejecuta ERC y revisa reportes

- **Agente GUI**
  - Abre KiCad
  - Navega entre hojas jerárquicas
  - Inserta símbolos desde la librería
  - Mueve, cablea y guarda cambios

## Qué debe poder hacer el agente GUI
En Windows, el agente debe tener capacidad de:
- abrir aplicaciones
- enfocar ventanas
- leer pantalla
- usar mouse y teclado
- opcionalmente tomar screenshots

## Flujo recomendado

### Fase 1. Lanzar KiCad
1. Abrir el proyecto:
   - `hardware/pcb/future_engineers_robotics_expansion.kicad_pro`
2. Entrar a Schematic Editor
3. Confirmar que se ven las hojas: `power`, `mcu`, `debug`, `imu`, `motors_4x`, `connectors`, `user_io`

### Fase 2. Hoja MCU
1. Abrir `mcu.kicad_sch`
2. Eliminar placeholder `U1`
3. Insertar símbolo:
   - `MCU_ST_STM32F1:STM32F103R_C-D-E_Tx`
4. Configurar campos:
   - `Reference = U1`
   - `Value = STM32F103RCT6`
   - `Footprint = Package_QFP:LQFP-64_10x10mm_P0.5mm`
5. Cablear:
   - `NRST -> NRST`
   - `BOOT0 -> BOOT0`
   - `PA13 -> SWDIO`
   - `PA14 -> SWCLK`
   - `PA9 -> UART_TX`
   - `PA10 -> UART_RX`
   - `PB6 -> IMU_SCL_SCLK`
   - `PB7 -> IMU_SDA_SDI`
   - `PB8 -> M1`
   - `PB0 -> M1A`
   - `PB1 -> M1B`
   - `VDD/VDDA/VBAT -> +3V3`
   - `VSS/VSSA -> GND/AGND`
6. Guardar

### Fase 3. Hoja IMU
1. Abrir `imu.kicad_sch`
2. Eliminar `U5` placeholder
3. Insertar símbolo:
   - `Sensor_Motion:ICM-20948`
4. Configurar campos:
   - `Reference = U5`
   - `Value = ICM-20948`
5. Cablear:
   - `SDO/AD0 -> IMU_AD0_SDO`
   - `SDA/SDI -> IMU_SDA_SDI`
   - `SCL/SCLK -> IMU_SCL_SCLK`
   - `~CS -> IMU_nCS`
   - `INT1 -> IMU_INT`
   - `VDDIO/VDD -> +3V3`
   - `GND -> GND`
6. Guardar

### Fase 4. Hoja motores_4x
1. Abrir `motors_4x.kicad_sch`
2. Mantener por ahora el bloque de `U6` o reemplazar si existe símbolo real del AM2861
3. Si no existe símbolo real:
   - conservar placeholder
   - ya está actualizado para reflejar `AM2861`
4. Cableado esperado:
   - `VM`
   - `GND/VGND`
   - `M1`
   - `M1A`
   - `M1B`
   - salidas `M1+`, `M1-`

### Fase 5. Conectores y debug
1. `debug.kicad_sch`
   - insertar header SWD real (`Conn_01x04` o `Conn_02x03`)
2. `connectors.kicad_sch`
   - batería: `Conn_01x02`
   - UART: `Conn_01x03`
   - motor/encoder: `Conn_01x06`

### Fase 6. Potencia
1. `power.kicad_sch`
2. Agregar:
   - protección por polaridad inversa
   - TVS `SMBJ14A`
   - capacitor bulk
   - buck 12V->5V
   - LDO 5V->3V3
3. Mantener coherencia con `power_architecture.md`

### Fase 7. Validación
1. Guardar todo
2. Ejecutar ERC
3. Corregir primero errores de símbolo faltante, pin sin conectar o tipos incompatibles

## Cómo coordinar con Cascade
Después de cada hoja, el agente GUI debe devolver uno de estos estados:
- `MCU listo`
- `IMU listo`
- `DEBUG listo`
- `CONNECTORS listo`
- `POWER listo`
- `Bloqueado: <motivo>`

Entonces Cascade:
- revisa siguiente paso
- ajusta mapeo si hace falta
- corre ERC cuando convenga

## Prompt corto para un agente GUI

```text
Actúa como operador de escritorio en Windows para KiCad 9.
No diseñes por tu cuenta.
Solo ejecuta exactamente las instrucciones técnicas que te iré dando.
Tu trabajo es:
1. abrir KiCad,
2. abrir el proyecto indicado,
3. entrar a la hoja indicada,
4. insertar el símbolo exacto indicado,
5. cablear solo las nets indicadas,
6. guardar,
7. reportar estado breve.

Reglas:
- No renombres nets por tu cuenta.
- No cambies hojas fuera de las indicadas.
- Si una librería no existe o no encuentras el símbolo, detente y reporta el bloqueo.
- Antes de borrar un placeholder, confirma visualmente la referencia del componente.
- Después de guardar cada hoja, responde solo con: "<HOJA> listo" o "Bloqueado: <motivo>".
```

## Limitación importante
Cascade no controla directamente la GUI de KiCad desde esta sesión. Necesita un agente de escritorio aparte o intervención tuya para los clics.

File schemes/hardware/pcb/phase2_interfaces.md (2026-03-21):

# Phase 2 Interfaces

## Global nets prepared
- `VM`
- `IN12V`
- `+5V`
- `+3V3`
- `GND`
- `DGND`
- `AGND`
- `VGND`
- `SWDIO`
- `SWCLK`
- `NRST`
- `BOOT0`
- `BOOT1`
- `UART_TX`
- `UART_RX`
- `IMU_INT`
- `IMU_SDA_SDI`
- `IMU_SCL_SCLK`
- `IMU_nCS`
- `IMU_AD0_SDO`
- `M1`
- `M1A`
- `M1B`
- `M1+`
- `M1-`
- `H1A`
- `H1B`

## MCU to sheets provisional pin planning
| Signal | MCU pin provisional | Direction at MCU | Origin sheet | Destination sheet |
|---|---|---|---|---|
| `+3V3` | `VDD_1..VDD_n` | input | `power` | `mcu` |
| `+5V` | `5V_AUX` | input | `power` | `mcu` |
| `GND` | `VSS_1..VSS_n` | bidirectional | `power` | `mcu` |
| `DGND` | `DGND_STAR` | bidirectional | `power` | `mcu` |
| `AGND` | `VSSA/AGND_REF` | bidirectional | `power` | `mcu` |
| `NRST` | `NRST` | bidirectional | `mcu` | `debug`, `user_io` |
| `BOOT0` | `BOOT0` | input | `debug` / `user_io` | `mcu` |
| `BOOT1` | `PB2 / BOOT1` | input | `debug` / `user_io` | `mcu` |
| `SWDIO` | `PA13` | bidirectional | `debug` | `mcu` |
| `SWCLK` | `PA14` | input | `debug` | `mcu` |
| `UART_TX` | `PA9 / USART1_TX` | output | `mcu` | `usb_uart`, `connectors` |
| `UART_RX` | `PA10 / USART1_RX` | input | `usb_uart`, `connectors` | `mcu` |
| `IMU_INT` | `PA3` | input | `imu` | `mcu` |
| `IMU_SDA_SDI` | `PB7 / I2C1_SDA` or `PA7 / SPI1_MOSI` | bidirectional | `mcu` | `imu` |
| `IMU_SCL_SCLK` | `PB6 / I2C1_SCL` or `PA5 / SPI1_SCK` | output | `mcu` | `imu` |
| `IMU_nCS` | `PA4 / SPI1_NSS` | output | `mcu` | `imu` |
| `IMU_AD0_SDO` | `PB5 / GPIO` or `PA6 / SPI1_MISO` | bidirectional | `imu` | `mcu` |
| `M1` | `PB8 / TIM4_CH3` | output | `mcu` | `motors_4x` |
| `M1A` | `PB0 / TIM3_CH3` | output | `mcu` | `motors_4x` |
| `M1B` | `PB1 / TIM3_CH4` | output | `mcu` | `motors_4x` |
| `H1A` | `PA0 / TIM2_CH1` | input | `motors_4x` / `connectors` | `mcu` |
| `H1B` | `PA1 / TIM2_CH2` | input | `motors_4x` / `connectors` | `mcu` |

## MCU to Motor 1 table
| Signal | MCU pin provisional | Direction | Origin sheet | Destination sheet |
|---|---|---|---|---|
| `M1` | `PB8 / TIM4_CH3` | output | `mcu` | `motors_4x` |
| `M1A` | `PB0 / TIM3_CH3` | output | `mcu` | `motors_4x` |
| `M1B` | `PB1 / TIM3_CH4` | output | `mcu` | `motors_4x` |
| `H1A` | `PA0 / TIM2_CH1` | input | `motors_4x` / `connectors` | `mcu` |
| `H1B` | `PA1 / TIM2_CH2` | input | `motors_4x` / `connectors` | `mcu` |
| `M1+` | `driver output` | output from motor stage | `motors_4x` | `connectors` |
| `M1-` | `driver output` | output from motor stage | `motors_4x` | `connectors` |

## MCU to IMU table
| Signal | MCU pin provisional | Direction | Origin sheet | Destination sheet |
|---|---|---|---|---|
| `IMU_INT` | `PA3` | input | `imu` | `mcu` |
| `IMU_SDA_SDI` | `PB7` or `PA7` | bidirectional | `mcu` | `imu` |
| `IMU_SCL_SCLK` | `PB6` or `PA5` | output | `mcu` | `imu` |
| `IMU_nCS` | `PA4` | output | `mcu` | `imu` |
| `IMU_AD0_SDO` | `PB5` or `PA6` | bidirectional | `imu` | `mcu` |

## Connector planning notes
- Battery / main power connector: pending `XT30` vs terminal block.
- SWD connector: 2.54 mm debug header baseline.
- UART external connector: simple `TX/RX/GND` header.
- Motor / encoder / compact peripherals: `JST-PH` baseline.

## Phase 2 boundaries by sheet
- `power`: power entry and derived rails only.
- `mcu`: central interface owner for SWD, UART, IMU, and Motor 1 control.
- `debug`: SWD + reset/boot access.
- `usb_uart`: optional serial bridge path only.
- `imu`: ICM20948 interface boundary only.
- `motors_4x`: treated as Motor 1-only motor stage boundary in this revision.
- `user_io`: minimum reset/boot access only.
- `connectors`: battery, UART, motor, and Hall/encoder external access.

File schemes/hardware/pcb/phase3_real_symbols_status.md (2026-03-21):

# Phase 3: Real Symbols Integration - Status Report

## Objective
Replace visual placeholder blocks with actual KiCad library symbols and connect their pins to hierarchical labels.

## Symbols Located in KiCad Libraries

### MCU - STM32F103RCT6
- **Library**: `C:\Program Files\KiCad\9.0\share\kicad\symbols\MCU_ST_STM32F1.kicad_sym`
- **Symbol Name**: `STM32F103R_C-D-E_Tx`
- **Line Range**: 54113-55545 (1432 lines)
- **Footprint**: `Package_QFP:LQFP-64_10x10mm_P0.5mm`
- **Key Pins for Wiring**:
  - Pin 7: NRST
  - Pin 60: BOOT0
  - Pin 46: PA13 (SYS_JTMS-SWDIO) → SWDIO
  - Pin 49: PA14 (SYS_JTCK-SWCLK) → SWCLK
  - Pin 42: PA9 (USART1_TX) → UART_TX
  - Pin 43: PA10 (USART1_RX) → UART_RX
  - Pin 58: PB6 (I2C1_SCL) → IMU_SCL_SCLK
  - Pin 59: PB7 (I2C1_SDA) → IMU_SDA_SDI
  - Pin 61: PB8 (TIM4_CH3) → M1 PWM
  - Pin 26: PB0 → M1A (Hall A)
  - Pin 27: PB1 → M1B (Hall B)
  - Power: VDD (pins 1,13,19,32,48,64), VSS (pins 18,31,47,63), VDDA (pin 13), VSSA (pin 12)

### IMU - ICM-20948
- **Library**: `C:\Program Files\KiCad\9.0\share\kicad\symbols\Sensor_Motion.kicad_sym`
- **Symbol Name**: `ICM-20948`
- **Line Range**: 2948-3410 (462 lines)
- **Footprint**: `Sensor_Motion:InvenSense_QFN-24_3x3mm_P0.4mm`
- **Key Pins for Wiring**:
  - Pin 9: SDO/AD0 → IMU_AD0_SDO
  - Pin 24: SDA/SDI → IMU_SDA_SDI
  - Pin 23: SCL/SCLK → IMU_SCL_SCLK
  - Pin 22: ~CS → IMU_nCS
  - Pin 12: INT1 → IMU_INT
  - Pin 8: VDDIO → +3V3
  - Pin 13: VDD → +3V3
  - Pin 18: GND → GND

### Connectors
- **Library**: `C:\Program Files\KiCad\9.0\share\kicad\symbols\Connector_Generic.kicad_sym`
- **Available Symbols**:
  - `Conn_01x02` - For battery connector (VM+, GND)
  - `Conn_01x03` - For UART header (GND, TX, RX)
  - `Conn_01x04` - For SWD header (VCC, SWDIO, SWCLK, GND)
  - `Conn_01x06` - For motor/encoder connector (VM, M+, M-, HA, HB, GND)

## Current Status

### Completed
- ✅ Located all required symbols in KiCad standard libraries
- ✅ Identified exact pin mappings for MCU → peripherals
- ✅ Documented symbol locations and line ranges

### In Progress
- 🔄 Replacing `U1` placeholder in `mcu.kicad_sch` with real STM32 symbol
  - **Challenge**: Generated files had formatting issues causing KiCad parse errors
  - **Next Approach**: Manual editing using `multi_edit` tool with exact S-expression syntax

### Pending
- ⏳ Replace `U5` placeholder in `imu.kicad_sch` with real ICM-20948 symbol
- ⏳ Replace connector placeholders in `debug.kicad_sch`, `connectors.kicad_sch`
- ⏳ Add wire connections between symbol pins and hierarchical labels
- ⏳ Run ERC validation
- ⏳ Generate final report

## Recommended Next Steps

### Option A: Manual Symbol Integration (Recommended)
1. Use KiCad GUI to open `mcu.kicad_sch`
2. Delete the `U1` placeholder block
3. Add symbol from library: `MCU_ST_STM32F1:STM32F103R_C-D-E_Tx`
4. Place at coordinates (64.77, 101.6)
5. Wire pins to existing hierarchical labels
6. Repeat for IMU and connectors
7. Run ERC

### Option B: Programmatic Integration (Current Attempt)
1. Extract complete symbol S-expression from library
2. Embed into `lib_symbols` section of `.kicad_sch`
3. Update symbol instance to reference embedded symbol
4. Add wire elements connecting pins to labels
5. Validate syntax and run ERC

## Files Modified
- `hardware/pcb/generate_mcu_real.py` - Script to generate MCU schematic (had formatting issues)
- `hardware/pcb/generate_imu_real.py` - Script to generate IMU schematic (had formatting issues)
- `hardware/pcb/mcu.kicad_sch.bak` - Backup of original placeholder version

## Files Ready for Integration
- Original placeholder schematics are intact and valid
- Symbol definitions extracted from KiCad libraries
- Pin mapping tables documented

## Conclusion
The real symbols are located and ready. The challenge is properly embedding them into the `.kicad_sch` files with correct S-expression syntax. Manual integration via KiCad GUI is the safest path forward, or careful programmatic editing with exact format matching.

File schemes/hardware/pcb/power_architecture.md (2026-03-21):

# Power Architecture - Expansion Board Rev A

## Overview
Arquitectura de potencia para placa de expansión robótica con batería 3S LiPo (12.6V max), Raspberry Pi 5, STM32F103RCT6, ICM-20948 IMU y motor JGB37-520 con encoder Hall.

## Power Entry & Protection Stage

### Input Connector
- **Type**: XT60 or XT30 connector
- **Voltage**: 3S LiPo (9V - 12.6V nominal)
- **Expected Current**: 8A peak (motor stall + RPi5 + peripherals)

### Protection Components

#### 1. Reverse Polarity Protection
**Option A (Recommended): P-Channel MOSFET**
- Component: SI2301DS or similar
- Advantage: ~0V drop, high efficiency
- Gate control: Simple resistor divider

**Option B: Schottky Diode**
- Component: MBRS340 (3A, 40V) or similar
- Disadvantage: ~0.3V drop, power loss
- Use if MOSFET complexity is not desired

#### 2. Transient Voltage Suppression (TVS)
- **Component**: SMBJ14A or SMAJ14A
- **Voltage**: 14V breakdown (protects against motor back-EMF spikes)
- **Placement**: Parallel to input, after reverse protection
- **Reason**: JGB37 motors generate voltage spikes >20V during braking/direction changes

#### 3. Resettable Fuse (PPTC)
- **Component**: MF-R080 or similar (0.8A hold, 1.6A trip) for logic
- **Component**: MF-R500 (5A hold, 10A trip) for motor line
- **Placement**: Series with input, before distribution

#### 4. Input Bulk Capacitor
- **Component**: 470µF - 1000µF electrolytic, 25V rated
- **Placement**: Immediately after protection stage
- **Purpose**: Absorb motor current transients and stabilize input

## Power Distribution Tree

### Main Power Rails

```
Battery (9-12.6V)
    │
    ├─── [Protection Stage] ───┐
    │                          │
    │                          ├─── VM (Motor Power) ──> Motor Drivers
    │                          │
    │                          └─── VIN_12V ──> Buck Converter
    │                                              │
    │                                              ├─── +5V (5A) ──> Raspberry Pi 5 + Hailo
    │                                              │                  │
    │                                              │                  └─── USB peripherals
    │                                              │
    │                                              └─── +5V ──> LDO Regulator
    │                                                            │
    │                                                            └─── +3V3 ──> STM32F103RCT6
    │                                                                          ICM-20948
    │                                                                          Logic level
    └─── GND (Star Ground Point)
```

### Regulator Specifications

#### Buck Converter: 12V → 5V
- **IC**: TPS54560 or equivalent
- **Output**: 5V @ 5A minimum
- **Efficiency**: >85% @ full load
- **Features**: 
  - Integrated FET
  - Adjustable switching frequency (500kHz recommended)
  - Enable pin for power sequencing
- **Input Cap**: 22µF ceramic + 100µF electrolytic
- **Output Cap**: 47µF ceramic + 100µF electrolytic
- **Inductor**: 10µH, 6A saturation current

#### LDO: 5V → 3.3V
- **IC**: AMS1117-3.3 or MCP1700-3302E
- **Output**: 3.3V @ 1A
- **Dropout**: <1.3V (AMS1117) or <0.35V (MCP1700)
- **Purpose**: Low-noise supply for MCU and IMU
- **Input Cap**: 10µF ceramic
- **Output Cap**: 10µF + 100nF ceramic (close to IC)

**Design Note**: The LDO fed from Buck output provides excellent noise filtering for sensitive analog components (IMU accelerometer/gyro). This two-stage approach prevents switching noise from corrupting sensor readings.

## Ground Architecture (Star Ground)

### Ground Planes Strategy
To prevent motor current return paths from causing voltage drops in logic ground:

1. **Power Ground (PGND)**: Heavy copper pour for motor drivers, battery return
2. **Analog Ground (AGND)**: Separate plane for IMU, ADC references
3. **Digital Ground (DGND)**: STM32, logic ICs
4. **Star Point**: All grounds connect at single point near battery connector

### PCB Layout Guidelines
- Keep motor driver ground traces wide (>2mm)
- Route AGND separately, connect to star point via ferrite bead or 0Ω resistor
- Place decoupling caps as close as possible to IC power pins
- Use ground vias liberally to connect top/bottom ground pours

## Decoupling Strategy

### Per-IC Requirements

#### STM32F103RCT6
- **VDD pins (1, 19, 32, 48, 64)**: 100nF ceramic each, close to pin
- **VDDA (pin 13)**: 100nF + 1µF ceramic + ferrite bead from VDD
- **VBAT (pin 1)**: 100nF ceramic
- **Bulk**: 10µF ceramic near MCU

#### ICM-20948 IMU
- **VDD (pin 13)**: 100nF + 1µF ceramic
- **VDDIO (pin 8)**: 100nF ceramic
- **Placement**: Caps within 5mm of IC

#### Raspberry Pi 5 Power Input
- **5V Rail**: 100µF electrolytic + 10µF ceramic at connector
- **USB Power**: Separate 47µF ceramic per USB port if available

## Motor Driver Considerations

### H-Bridge Selection Criteria
For JGB37-520 motor (3.2A stall current):

**Recommended IC: AM2861 (Primary Choice)**
- **Current Rating**: 5A continuous, 8A peak
- **Voltage Range**: 2.5V - 15V (perfect for 3S LiPo)
- **R_ds(on)**: ~0.15Ω (low heat dissipation)
- **Package**: SOP-8 (easy to solder, good thermal performance)
- **Features**:
  - Built-in protection: overcurrent, thermal shutdown, undervoltage lockout
  - PWM frequency up to 100kHz (low audible noise)
  - Logic-level inputs (3.3V compatible with STM32)
  - No external Schottky diodes needed (integrated body diodes)
- **Advantages over alternatives**:
  - **vs DRV8871**: Higher current rating (5A vs 3.6A), lower cost
  - **vs TB6612FNG**: Much higher current per channel (5A vs 1.2A)
  - **vs L298N**: Much lower dropout (~0.3V vs 2V), higher efficiency

**Alternative ICs** (if AM2861 not available):
- **DRV8871** (Single H-bridge, 3.6A continuous, 6.5A peak)
- **TB6612FNG** (Dual H-bridge, 1.2A continuous, 3.2A peak per channel)
- **BTS7960** (High-power, 43A, overkill but robust)

**Thermal Management**:
- Add thermal vias under driver IC pad (minimum 9 vias, 0.3mm diameter)
- Copper pour on bottom layer connected to GND for heat spreading
- Calculate power dissipation: P_loss = I²_rms × R_ds(on) × 2 (for H-bridge)
  - AM2861 @ 2A: (2A)² × 0.15Ω × 2 = **1.2W** (manageable without heatsink)
  - DRV8871 @ 2A: (2A)² × 0.3Ω × 2 = **2.4W** (needs better cooling)

### Motor Power Filtering
- **Bulk Cap**: 220µF electrolytic at motor driver VIN
- **Ceramic**: 1µF ceramic for high-frequency switching noise
- **Flyback Diodes**: Integrated in modern H-bridges, verify in datasheet

## Checklist de Potencia - Rev A

### Protection Stage
- [ ] Diodo Schottky o MOSFET de protección contra inversión de polaridad
- [ ] Diodo TVS de 14V-15V (SMBJ14A) para picos de motores
- [ ] Fusible PPTC (5A-10A) en línea de entrada
- [ ] Capacitor electrolítico grande (470µF - 1000µF, 25V) en entrada de 12V

### Regulators
- [ ] Buck converter 12V→5V con TPS54560 o equivalente (5A mínimo)
- [ ] Inductor de 10µH, 6A para Buck
- [ ] LDO 5V→3.3V con AMS1117-3.3 o MCP1700
- [ ] Capacitor de 10µF + 100nF a la entrada y salida de cada regulador

### MCU Power
- [ ] El STM32 tiene un capacitor de 100nF en cada pin VDD/VDDA
- [ ] VDDA con ferrite bead desde VDD
- [ ] Capacitor bulk de 10µF cerca del MCU

### IMU Power
- [ ] 100nF + 1µF en VDD del ICM-20948
- [ ] 100nF en VDDIO del ICM-20948
- [ ] Caps dentro de 5mm del IC

### Ground Strategy
- [ ] Star ground implementado cerca del conector de batería
- [ ] PGND separado para motores (trazas anchas >2mm)
- [ ] AGND para IMU conectado via ferrite bead o 0Ω
- [ ] Vias de ground abundantes entre capas

### Motor Driver
- [ ] H-bridge AM2861 seleccionado (5A continuo, 8A pico)
- [ ] Mínimo 9 vias térmicos (0.3mm) bajo pad del driver
- [ ] Copper pour en capa inferior para disipación térmica
- [ ] Capacitor bulk 220µF en VIN del driver
- [ ] Capacitor cerámico 1µF para ruido de conmutación
- [ ] Entradas PWM/DIR conectadas a pines timer del STM32 (PB8 para PWM)

## Component Selection Summary

| Function | Component | Package | Quantity | Notes |
|---|---|---|---|---|
| Reverse Protection | SI2301DS | SOT-23 | 1 | P-MOSFET |
| TVS Diode | SMBJ14A | DO-214AA | 1 | 14V breakdown |
| PPTC Fuse | MF-R500 | 1206 | 1 | 5A hold |
| Input Cap | 1000µF/25V | Electrolytic | 1 | Low ESR |
| Buck IC | TPS54560 | SOIC-8 | 1 | 5A output |
| Buck Inductor | 10µH/6A | SMD | 1 | Low DCR |
| LDO | AMS1117-3.3 | SOT-223 | 1 | 1A output |
| Decoupling | 100nF/50V | 0805 | 15+ | Ceramic X7R |
| Decoupling | 10µF/16V | 0805 | 8+ | Ceramic X7R |
| Motor Driver | DRV8871 | HTSSOP-8 | 1 | 3.6A continuous |

## Design Validation Tests

### Pre-Assembly
1. Verify polarity protection with multimeter (reverse battery should show open circuit)
2. Check TVS clamping voltage with bench supply and scope

### Post-Assembly
1. Power-up sequence test: Measure 12V → 5V → 3.3V rise times
2. Load test: Apply 2A load to 5V rail, verify <5% voltage drop
3. Motor transient test: Run motor forward/reverse, capture voltage spikes on scope
4. Thermal test: Run motor at stall for 10s, measure driver IC temperature
5. IMU noise test: Read accelerometer data while motor running, check for interference

## References
- AM2861 Datasheet: https://www.alldatasheet.com/datasheet-pdf/pdf/1132890/ANACHIP/AM2861.html
- TPS54560 Datasheet: https://www.ti.com/lit/ds/symlink/tps54560.pdf
- DRV8871 Datasheet (alternative): https://www.ti.com/lit/ds/symlink/drv8871.pdf
- STM32F103 Power Guidelines: AN2867
- ICM-20948 Hardware Integration: DS-000189

## Revision History
- **Rev A** (2026-03-15): Initial architecture definition

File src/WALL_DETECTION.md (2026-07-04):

# Lidar Wall Detection — Implementation Notes

This document describes the wall-detection and slope/orientation-following logic in
`software/cpp/object_detection/object_detection.cpp`, and the important tunable
variables if detection needs to be re-calibrated (new lidar unit, new arena lighting/
surfaces, different robot chassis, etc).

It covers two related but separate pipelines in the same file:

1. **`Select_Wall()` / `Slope()` / `Distance_To_Wall()`** — the robot's live
   decision-making path: "which wall is on my `front`/`right`/`left`/`behind`, what's
   its orientation, and how far away is it."
2. **`postprocess_callback()`'s lidar visualization** — a separate, independent wall
   detector used only to draw the debug "Lidar Coordinates" window. It exists purely
   to let a human see what the lidar sees; it does not feed the robot's control logic.

Both pipelines follow the same general recipe (filter noise → group points into
candidate walls → score/pick the best one), but they are two independent
implementations with their own tuning constants — a fix in one does not
automatically apply to the other.

---

## 1. The `direction side` API

All wall queries take a single `direction` enum value instead of raw lidar angles:

```cpp
enum direction{
    right = 1,
    left = -1,
    front = 2,
    behind = -2,
    invalid = 0
};
```

- `float Slope(const direction side)` — the selected wall's orientation, in degrees.
- `float Distance_To_Wall(const direction side)` — perpendicular distance (mm) from
  the robot to the selected wall's fitted line.
- `void Print_Slope(const direction side)` / `void Follow_Wall(const direction side)` —
  thin wrappers used by the robot's control loop.

Internally, `side` is mapped to a raw lidar angle (`middle_point`) in `Select_Wall()`:

```cpp
switch (side) {
    case right:  middle_point = 0;   break;
    case left:   middle_point = 180; break;
    case front:  middle_point = 270; break;
    case behind: middle_point = 90;  break;
}
```

**This mapping is specific to the current lidar's physical mounting** on the robot
(currently the Oradar S2L). It was found empirically: the lidar's raw 0° reference
does not line up with the robot's actual front, and it was determined by placing a
single test object directly against the robot's front bumper and reading which raw
angle lit up (a single isolated object gives an unambiguous reading; inferring the
offset from a busy multi-wall room scene is much easier to get wrong).

**If the lidar is replaced or reseated, re-derive this mapping** — do not assume the
old values still apply. Re-run the same test: an isolated object against a known
side (front bumper is easiest), read its angle off the "Lidar Coordinates" window,
and set that side's case to the observed angle.

---

## 2. `Select_Wall()` — the robot-facing wall detector

`Select_Wall(side)` is the shared core behind `Slope()` and `Distance_To_Wall()` — both
call it and read different results off the same selection, so they can never disagree
about which wall was chosen. Its steps, in order:

### 2.1 Build an angular window around the requested side

```cpp
const int point = 70;              // total window width, in degrees
const int half_point = point / 2;  // window is centered on middle_point, not one-sided
```

The window spans `[middle_point - half_point, middle_point + half_point)`. It must
stay well under 90° because the four sides are only 90° apart — too wide a window and
adjacent sides start reading each other's walls (this happened once when `point` was
170; narrowing it to 70 fixed cross-talk between sides at the cost of some coverage
on very long walls near a direction boundary).

```cpp
const int middle_exclusion_deg = 3;
```
Points within 3° of the exact center angle are dropped — that spot is often a seam or
corner between two walls, and including it can pull in a small noisy cluster.

### 2.2 Filter out the robot's own chassis

```cpp
const float min_range_mm = 150.0f;
```
Anything closer than this is almost certainly the robot's own body/mount, not an
environmental wall. These near-origin returns are trivially "clean" (a rigid nearby
surface fits a line almost perfectly), so without this filter they would out-score
real walls every time. **If the lidar is mounted differently, or a new chassis has a
different self-obstruction distance, re-check this value.**

### 2.3 Radius Outlier Removal (ROR)

```cpp
const float ror_radius_mm = 300.0f;
const int   ror_min_neighbors = 3;
```
A point is dropped if it has fewer than `ror_min_neighbors` other points within
`ror_radius_mm` of it. This prevents a single stray noisy point from triggering a
false gap/corner split and shattering a real wall into fragments.

```cpp
const int edge_pad_deg = 15;
```
ROR needs neighbors on *both* sides of a point to judge it fairly. A real wall point
sitting at the edge of the window has neighbors just *outside* the window — without
padding, it looks falsely isolated and gets dropped, truncating real walls right at
the window boundary. So the code collects a padded range purely to support neighbor
counting, then trims back to the actually-requested window (`pt_is_core`) before
scoring.

### 2.4 Segment into candidate walls

```cpp
const float gap_threshold_mm = 60.0f;
```
Gap-based segmentation: a new wall segment starts wherever consecutive points jump
apart by more than this distance.

```cpp
const float corner_split_threshold_mm = 40.0f;
const int   corner_margin_points = 2;
```
Each gap-segment is further split at corners — an orientation change with *no* range
gap (two walls meeting at a corner have continuous range but different angle) —
using a recursive max-perpendicular-deviation split (Iterative End-Point Fit). A few
points straddling the detected corner vertex are dropped, since corner-adjacent
returns tend to be noisy/transitional.

### 2.5 Score and filter candidates

```cpp
const float max_wall_residual_mm = 15.0f;
const int   min_wall_points = 6;
const float min_wall_extent_mm = 200.0f;
```
- **`min_wall_points`**: segments smaller than this are excluded entirely. This must
  be high enough that residual is actually meaningful — a 2-3 point segment is
  geometrically almost a perfect line no matter what, so tiny fragments are
  structurally biased toward looking "clean" even though they prove nothing.
- **`max_wall_residual_mm`**: a segment "qualifies" if its RMS perpendicular
  distance to its own best-fit line is under this. Qualifying segments always
  outrank non-qualifying ones.
- **`min_wall_extent_mm`**: a segment must span at least this far end-to-end to
  count as a wall. This exists because a compact object (a box, a pillar, another
  robot) can rack up enough points within the ROR radius to pass `min_wall_points`
  and still look "clean" by residual — neither of those checks can tell a wall from
  a blob on their own. Requiring physical extent directly excludes objects,
  independent of point count or residual.

Among qualifying candidates, ranking prefers **more points** first, then lower
residual as a tiebreaker only — point count is never overridden by residual alone,
since that's what previously let tiny clean fragments beat real, longer (slightly
noisier) walls.

### 2.6 Per-side wall tracking (avoids flipping to the adjacent wall)

```cpp
const float wall_track_max_match_mm = 300.0f;
const float wall_track_max_angle_diff_deg = 20.0f;
```
Once a wall has been chosen for a given `side`, the next call prefers to keep
following *that same physical wall* (matched by centroid position + orientation)
rather than always snapping to whichever segment scores best this frame. This
matters because a few degrees of robot rotation can shift the fixed angular window
enough that an adjacent wall briefly outscores the wall actually being followed,
which previously caused a visible flip mid-turn. If the previously-tracked wall
can't be matched within `wall_track_max_match_mm` / `wall_track_max_angle_diff_deg`
(e.g. it genuinely left the window), the code falls back to the best-scoring
candidate and starts tracking that instead — so it still self-recovers.

Tracking state is keyed per-`side` (a `static std::unordered_map<int, WallTrackState>`
inside `Select_Wall`), so `front`/`right`/`left`/`behind` each track their own wall
independently.

### 2.7 Merge a split wall, but not a real corner

```cpp
const float max_merge_angle_diff_deg = 12.0f;
```
The chosen wall's points are merged with one other candidate segment (the
top-scoring one, or the second-best if the chosen wall already is the top scorer)
**only if** the two segments' independently-fit orientations agree within this
threshold. This handles a wall that got split into two segments by a sensor dropout
without incorrectly merging two genuinely different walls meeting at a corner
(which would fit a meaningless line through neither surface).

### 2.8 Outputs

- `Slope(side)` returns `Fit_Line_Orientation()` on the final chosen points — a
  total-least-squares (PCA) line-direction fit, robust to which axis has more
  variance.
- `Distance_To_Wall(side)` returns the perpendicular distance from the robot's
  origin to that same fitted line (not just the centroid's range, since the
  centroid can sit off to one side of the perpendicular foot).
- `Publish_Slope_Used_Angles()` records exactly which raw lidar angles fed the
  result, so the visualization can highlight precisely those points (see below).

---

## 3. The visualization's wall detector (`postprocess_callback`)

This is a **separate implementation** that scans the *entire* 360° buffer (not a
narrow window around one side) purely to draw the "Lidar Coordinates" debug window.
It is not used by `Slope()`/`Distance_To_Wall()` and tuning it does not affect robot
behavior — only what you see on screen.

```cpp
const float ror_radius_mm = 100.0f;
const int   ror_min_neighbors = 10;
```
Its own ROR pass (different radius/neighbor values than `Select_Wall`'s).

```cpp
const float bpd_lambda_deg = 10.0f;   // min incidence angle assumed for a flat surface
const float bpd_sigma_r_mm = 10.0f;   // range measurement noise estimate
```
Uses the Adaptive Breakpoint Detector (Borges & Aldon) instead of a flat gap
threshold: the maximum allowed gap between consecutive points (`D_max`) is computed
per-point from range and incidence-angle geometry, rather than being a single fixed
distance. **A smaller `bpd_lambda_deg` makes `D_max` larger** (more tolerant of gaps,
less likely to split) — this was raised from 5° to 10° after a nearby test object
failed to split from an adjacent wall (at 5°, a ~450mm-range point had `D_max`≈142mm,
generous enough to merge a real object into the wall next to it).

```cpp
const int max_walls = 8;
const float wall_track_max_match_mm = 400.0f;
```
Keeps only the `max_walls` largest segments as "real" walls (everything else is
drawn as grey clutter). Also does its own centroid-based color tracking
(`wall_tracks`) so the same physical wall keeps the same color across frames instead
of flickering when two similarly-sized walls swap size-rank — conceptually similar
to `Select_Wall`'s per-side tracking in §2.6, but keyed by color slot rather than by
`side`, and only used for rendering.

### Highlighted-wall distance overlay

Whenever `Slope()`/`Distance_To_Wall()` has highlighted a wall (the black-outlined
points in the debug view — driven by `Publish_Slope_Used_Angles`), the visualization
independently computes the perpendicular distance from the origin to that
highlighted wall's fitted line, and:

- prints it to the terminal: `[Highlighted wall] distance=512mm`
- draws it as text on the canvas, in the same color as the highlighted wall.

This is a display-only echo of the same perpendicular-distance math used in
`Distance_To_Wall()` — it's recomputed here only so the overlay works even when
nothing has called `Distance_To_Wall()` this frame.

---

## 4. Mathematical formulas

This section gives the actual math behind each step in §2/§3, using the raw lidar
return `(angle_deg, range_mm)` as the starting point. Points are indexed `i = 1..N`
within whatever set is being processed (a window, a segment, etc.).

### 4.1 Polar → Cartesian conversion

Every raw `(angle, range)` return is converted to a 2D point in the lidar's own
frame (mm), robot origin at `(0, 0)`, before any of the steps below run:

```
x_i = range_i * cos(angle_i)
y_i = range_i * sin(angle_i)
```

### 4.2 Radius Outlier Removal (ROR)

For each point `i`, count how many other points `j` fall within `ror_radius_mm`:

```
neighbor_count(i) = | { j != i : ||p_i - p_j|| <= ror_radius_mm } |

||p_i - p_j|| = sqrt( (x_i - x_j)^2 + (y_i - y_j)^2 )   (Euclidean distance)
```

Point `i` is kept only if `neighbor_count(i) >= ror_min_neighbors`; otherwise it's
discarded as an outlier.

### 4.3 Gap-based segmentation

A new segment starts between consecutive points `i-1` and `i` whenever:

```
||p_i - p_{i-1}|| > gap_threshold_mm
```

### 4.4 Adaptive Breakpoint Detector (visualization only, Borges & Aldon 2004)

Instead of one fixed gap threshold, the maximum allowed distance between
consecutive points `D_max` is derived per-point from range and an assumed minimum
surface incidence angle `λ` (`bpd_lambda_deg`):

```
Δφ = angle_i - angle_{i-1}                       (angular step between returns)

D_max = r_{i-1} * sin(Δφ) / sin(λ - Δφ)  +  3 * σ_r      if Δφ < λ
D_max = -1  (never split; treat as "infinite gap allowed")   if Δφ >= λ
```

where `r_{i-1}` is the previous point's range and `σ_r` is `bpd_sigma_r_mm` (assumed
range measurement noise). A new segment starts if `||p_i - p_{i-1}|| > D_max`.
Intuition: a flat surface seen at a shallow (near-parallel) incidence angle
naturally produces bigger point-to-point spacing than one viewed head-on, at the
same range — `D_max` grows accordingly so a real continuous wall isn't falsely
split, while `λ` sets the floor below which any gap at all is treated as a break.

**Why a smaller `λ` makes the detector more tolerant:** for fixed `Δφ` < `λ`,
shrinking `λ` shrinks `(λ - Δφ)`, which shrinks `sin(λ - Δφ)` (for small angles,
`sin` is roughly linear), which appears in `D_max`'s *denominator* — so `D_max`
grows. A larger `D_max` means more real gaps get "explained away" as an artifact of
viewing angle rather than a genuine break in the surface, which is exactly what let
a nearby test object merge into the wall next to it at `λ = 5°`.

### 4.5 Corner splitting (Iterative End-Point Fit / split-and-merge)

For a segment with endpoints `p_1` and `p_n`, every interior point `p_k` is scored
by its perpendicular distance to the straight line `p_1 → p_n`:

```
line_dir = p_n - p_1
dist(p_k) = | line_dir × (p_k - p_1) | / ||line_dir||

  where a × b = a.x * b.y - a.y * b.x     (2D cross product, gives a scalar)
```

The point with the largest `dist(p_k)` is the candidate corner. If
`max(dist) > corner_split_threshold_mm`, the segment is split there (dropping
`corner_margin_points` points on each side of the split index), and the same test
is applied recursively to both halves.

### 4.6 Total Least Squares (PCA) line orientation fit

**Why not ordinary least squares?** Fitting `y = mx + b` minimizes *vertical*
distance and blows up (`m → ∞`) for a wall running nearly parallel to the y-axis —
which happens constantly here, since a wall can face the robot at any angle. Total
Least Squares instead minimizes *perpendicular* distance to the line, which has no
preferred axis and works identically at any orientation. This is exactly what PCA
gives you: the line through the centroid along the direction of maximum variance is
also the line that minimizes total squared perpendicular distance to it.

**Step 1 — center the points.** Given the mean `(x̄, ȳ)` of the segment's `N` points,
form the centered coordinates:

```
dx_i = x_i - x̄
dy_i = y_i - ȳ
```

**Step 2 — build the 2×2 covariance (scatter) matrix.**

```
        [ S_xx  S_xy ]
  C  =  [ S_xy  S_yy ]

S_xx = Σ dx_i^2  ,   S_yy = Σ dy_i^2  ,   S_xy = Σ dx_i * dy_i
```

(these are the unnormalized covariances — dividing by `N` would give the usual
covariance matrix, but the scale doesn't affect the eigenvectors, so the division is
skipped).

**Step 3 — find the eigenvector of `C` with the largest eigenvalue.** For a general
point cloud, PCA proceeds by eigen-decomposing `C`. For a symmetric 2×2 matrix this
has a closed form instead of needing iterative eigen-solvers:

```
eigenvalues:  λ± = (S_xx + S_yy)/2  ±  sqrt( ((S_xx - S_yy)/2)^2 + S_xy^2 )
```

`λ+` (the larger root) is the variance *along* the wall's direction; `λ-` is the
(ideally small) variance *across* it — i.e. the noise. The eigenvector belonging to
`λ+` points along the wall. Rather than solving `(C - λ+ I) v = 0` directly for that
eigenvector, the code uses the standard double-angle identity for diagonalizing a
symmetric 2×2 matrix by rotation: the rotation angle `θ` that diagonalizes `C`
(equivalently, the direction of its dominant eigenvector) satisfies:

```
tan(2θ) = 2*S_xy / (S_xx - S_yy)

θ = 0.5 * atan2( 2 * S_xy,  S_xx - S_yy )
```

using `atan2` (rather than plain `atan`) so the correct quadrant is picked up
automatically across the full 180° range of possible wall orientations.

`θ` (converted to degrees) is the line's orientation — the axis of maximum variance
through the points, equivalently the total-least-squares best-fit line direction.
Because a line and its 180°-rotated reverse describe the same orientation, `θ` is
only meaningful modulo 180° (see the wraparound handling in §4.9).

### 4.7 Line-fit residual (RMS perpendicular error)

Using the same `θ` from §4.6, the unit normal to the fitted line is
`n = (-sin θ, cos θ)`. Each point's signed perpendicular distance to the line
through the centroid is:

```
r_i = dx_i * n.x + dy_i * n.y

residual = sqrt( (1/N) * Σ r_i^2 )     (RMS of the r_i)
```

A segment "qualifies" as a clean wall if `residual <= max_wall_residual_mm`.

### 4.8 Perpendicular distance from the robot to the wall

`Distance_To_Wall()` and the visualization's highlighted-wall overlay both compute
the distance from the origin (the robot) to the wall's fitted *line* (not to the
wall's centroid point), using the same unit direction vector `dir = (cos θ, sin θ)`
from §4.6 and the segment's centroid `(x̄, ȳ)`:

```
distance = | x̄ * dir.y  -  ȳ * dir.x |
```

This is the magnitude of the 2D cross product of the centroid position with the
line's direction vector — geometrically, the length of the perpendicular dropped
from the origin onto the infinite line through the centroid along `dir`.

### 4.9 Wall-identity matching (tracking)

Both `Select_Wall`'s per-side tracking (§2.6) and the visualization's color
tracking match a candidate segment `c` against a previously-tracked wall `t` using
two independent criteria that must both pass:

```
position_match:  ||centroid_c - centroid_t|| <= wall_track_max_match_mm

angle_diff = | orientation_c - orientation_t |
if angle_diff > 90°:  angle_diff = 180° - angle_diff      (line orientation is mod 180°,
                                                             a line and its reverse are
                                                             the same orientation)
orientation_match:  angle_diff <= wall_track_max_angle_diff_deg
```

Among all candidates satisfying both, the one with the smallest `position_match`
distance is chosen as the continuation of the tracked wall.

### 4.10 Angle classification (side labeling)

Given a wall's centroid, its angle from the robot is `atan2(ȳ, x̄)` (normalized to
`[0°, 360°)`). To classify which `side` it's nearest to, the angular difference to
each reference angle (`front=270°, right=0°, left=180°, behind=90°`) is computed
with wraparound handled the same way as §4.9:

```
diff(a, ref) = | a - ref |
if diff > 180°:  diff = 360° - diff

side = argmin_ref  diff(a, ref)
```

---

## 5. Quick reference: constants likely to need re-tuning

| Constant | Location | Current value | Purpose |
|---|---|---|---|
| `middle_point` per `side` | `Select_Wall` switch | front=270, right=0, left=180, behind=90 | Lidar-mount-specific angle offset — **re-derive if the lidar is replaced/reseated** |
| `point` | `Select_Wall` | 70° | Angular window width per side |
| `min_range_mm` | `Select_Wall` | 150mm | Excludes robot's own chassis |
| `ror_radius_mm` / `ror_min_neighbors` | `Select_Wall` | 300mm / 3 | Outlier rejection |
| `gap_threshold_mm` | `Select_Wall` | 60mm | Gap-based wall segmentation |
| `corner_split_threshold_mm` | `Select_Wall` | 40mm | Corner detection sensitivity |
| `min_wall_points` | `Select_Wall` | 6 | Minimum points to be considered a wall |
| `max_wall_residual_mm` | `Select_Wall` | 15mm | Max noise for a wall to "qualify" |
| `min_wall_extent_mm` | `Select_Wall` | 200mm | Minimum physical size (excludes objects) |
| `wall_track_max_match_mm` / `_angle_diff_deg` | `Select_Wall` | 300mm / 20° | Wall-identity tracking per side |
| `max_merge_angle_diff_deg` | `Select_Wall` | 12° | When two segments merge into one wall |
| `ror_radius_mm` / `ror_min_neighbors` | `postprocess_callback` (visualization only) | 100mm / 10 | Visualization-only outlier rejection |
| `bpd_lambda_deg` | `postprocess_callback` (visualization only) | 10° | Visualization-only gap tolerance |
| `max_walls` | `postprocess_callback` (visualization only) | 8 | How many walls get distinct colors on screen |

When re-tuning, change one constant at a time and re-test against a known scene —
several of these interact (e.g. widening `point` reduces directional selectivity;
loosening `ror_radius_mm` can let a small object pass `min_wall_extent_mm`'s
neighbor-density prerequisite).

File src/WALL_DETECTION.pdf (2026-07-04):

# Lidar Wall Detection — Implementation Notes

This document describes the wall-detection and slope/orientation-following logic in software/cpp/object_detection/object_detection.cpp , and the important tunable variables if detection needs to be re-calibrated (new lidar unit, new arena lighting/ surfaces, different robot chassis, etc).

It covers two related but separate pipelines in the same file:

1. Select_Wall() / Slope() / Distance_To_Wall() — the robot's live decision-making path: "which wall is on my front / right / left / behind , what's its orientation, and how far away is it."
2. postprocess_callback() 's lidar visualization — a separate, independent wall detector used only to draw the debug "Lidar Coordinates" window. It exists purely to let a human see what the lidar sees; it does not feed the robot's control logic.

Both pipelines follow the same general recipe (filter noise → group points into candidate walls → score/pick the best one), but they are two independent implementations with their own tuning constants — a fix in one does not automatically apply to the other.

### 1. The direction side API

All wall queries take a single direction enum value instead of raw lidar angles:

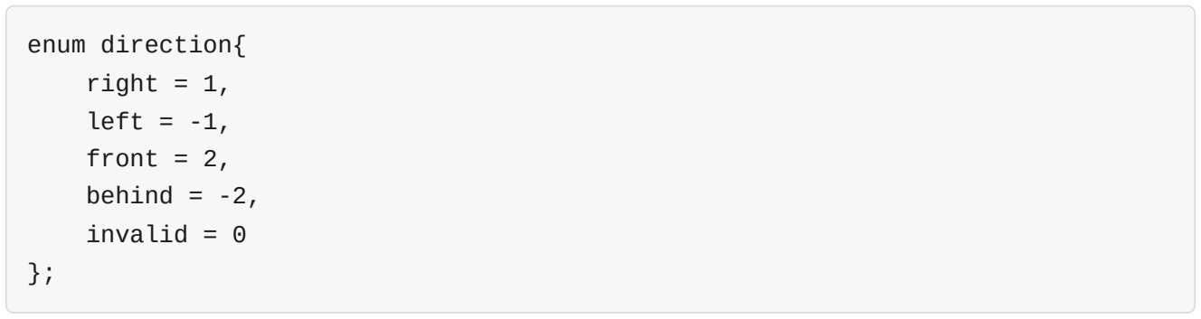
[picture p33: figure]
enum direction{ right = 1, left = -1, front = 2, behind = -2, invalid = 0

float Slope(const direction side) — the selected wall's orientation, in degrees. float Distance_To_Wall(const direction side) — perpendicular distance (mm) from the robot to the selected wall's fitted line.

void Print_Slope(const direction side) / void Follow_Wall(const direction side) — thin wrappers used by the robot's control loop.

Internally, side is mapped to a raw lidar angle ( middle_point ) in Select_Wall() :

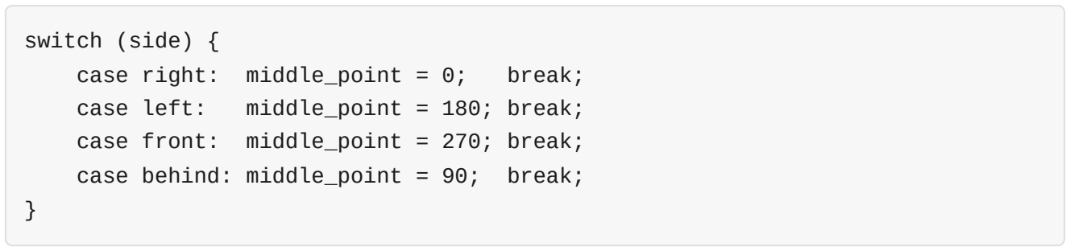
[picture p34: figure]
switch (side) {; case right: middle_point = 0;; break;; case left:; middle_point = 180; break;; case front: middle_point = 270; break; case behind: middle_point = 90; break;

This mapping is specific to the current lidar's physical mounting on the robot (currently the Oradar S2L). It was found empirically: the lidar's raw 0° reference does not line up with the robot's actual front, and it was determined by placing a single test object directly against the robot's front bumper and reading which raw angle lit up (a single isolated object gives an unambiguous reading; inferring the offset from a busy multi-wall room scene is much easier to get wrong).

If the lidar is replaced or reseated, re-derive this mapping — do not assume the old values still apply. Re-run the same test: an isolated object against a known side (front bumper is easiest), read its angle off the "Lidar Coordinates" window, and set that side's case to the observed angle.

### 2. Select_Wall() — the robot-facing wall detector

Select_Wall(side) is the shared core behind Slope() and Distance_To_Wall() — both call it and read different results off the same selection, so they can never disagree about which wall was chosen. Its steps, in order:

### 2.1 Build an angular window around the requested side

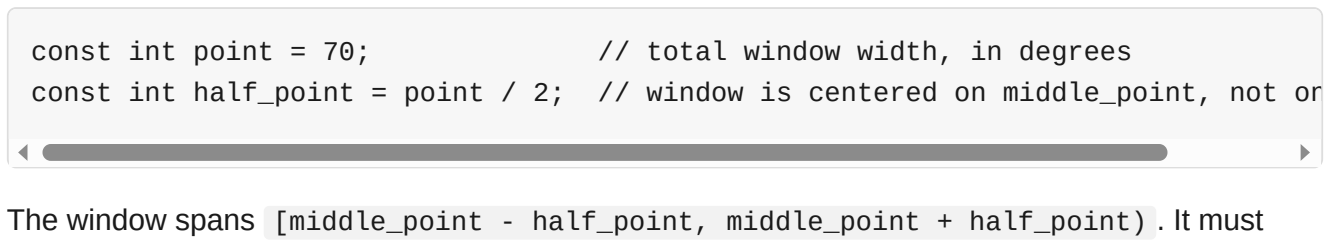
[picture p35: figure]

const int point = 70; | // total window width, in degrees
const int half_point = point / 2; // window is centered on middle_point, not on

The window spans [middle_point - half_point, middle_point + half_point) . It must stay well under 90° because the four sides are only 90° apart — too wide a window and adjacent sides start reading each other's walls (this happened once when point was 170; narrowing it to 70 fixed cross-talk between sides at the cost of some coverage on very long walls near a direction boundary).

const int middle_exclusion_deg = 3;

Points within 3° of the exact center angle are dropped — that spot is often a seam or corner between two walls, and including it can pull in a small noisy cluster.

### 2.2 Filter out the robot's own chassis

const float min_range_mm = 150.0f;

Anything closer than this is almost certainly the robot's own body/mount, not an environmental wall. These near-origin returns are trivially "clean" (a rigid nearby surface fits a line almost perfectly), so without this filter they would out-score real walls every time. If the lidar is mounted differently, or a new chassis has a different self-obstruction distance, re-check this value.

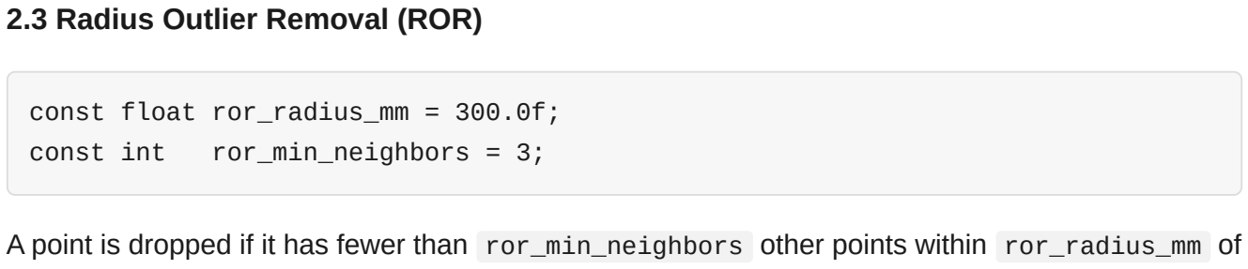
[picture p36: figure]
2.3 Radius Outlier Removal (ROR); const float ror_radius_mm = 300.0f;; const int; ror_min_neighbors = 3;

A point is dropped if it has fewer than ror_min_neighbors other points within ror_radius_mm of it. This prevents a single stray noisy point from triggering a false gap/corner split and shattering a real wall into fragments.

const int edge_pad_deg = 15;

ROR needs neighbors on both sides of a point to judge it fairly. A real wall point sitting at the edge of the window has neighbors just outside the window — without padding, it looks falsely isolated and gets dropped, truncating real walls right at the window boundary. So the code collects a padded range purely to support neighbor counting, then trims back to the actually-requested window ( pt_is_core ) before scoring.

### 2.4 Segment into candidate walls

const float gap_threshold_mm = 60.0f;

Gap-based segmentation: a new wall segment starts wherever consecutive points jump apart by more than this distance.

Each gap-segment is further split at corners — an orientation change with no range gap (two walls meeting at a corner have continuous range but different angle) — using a recursive max-perpendicular-deviation split (Iterative End-Point Fit). A few points straddling the detected corner vertex are dropped, since corner-adjacent returns tend to be noisy/transitional.

### 2.5 Score and filter candidates

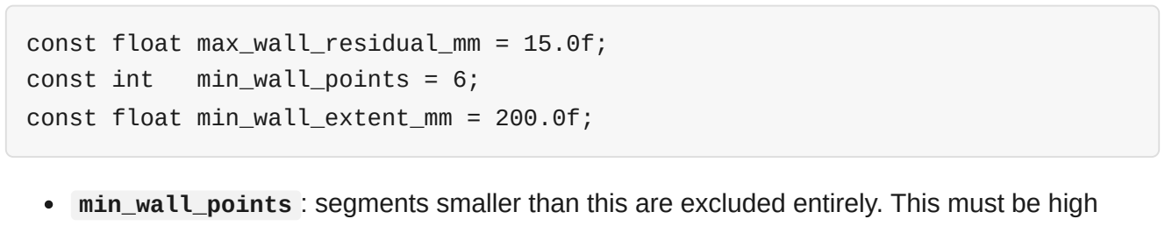
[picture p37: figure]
const float max_wall_residual_mm = 15.0f;; const int; min_wall_points = 6;; const float min_wall_extent_mm = 200.0f;

min_wall_points : segments smaller than this are excluded entirely. This must be high enough that residual is actually meaningful — a 2-3 point segment is geometrically almost a perfect line no matter what, so tiny fragments are structurally biased toward looking "clean" even though they prove nothing.
max_wall_residual_mm : a segment "qualifies" if its RMS perpendicular distance to its own best-fit line is under this. Qualifying segments always outrank non-qualifying ones. min_wall_extent_mm : a segment must span at least this far end-to-end to count as a wall. This exists because a compact object (a box, a pillar, another robot) can rack up enough points within the ROR radius to pass min_wall_points and still look "clean" by residual — neither of those checks can tell a wall from a blob on their own. Requiring physical extent directly excludes objects, independent of point count or residual.

Among qualifying candidates, ranking prefers more points first, then lower residual as a tiebreaker only — point count is never overridden by residual alone, since that's what previously let tiny clean fragments beat real, longer (slightly noisier) walls.

### 2.6 Per-side wall tracking (avoids flipping to the adjacent wall)

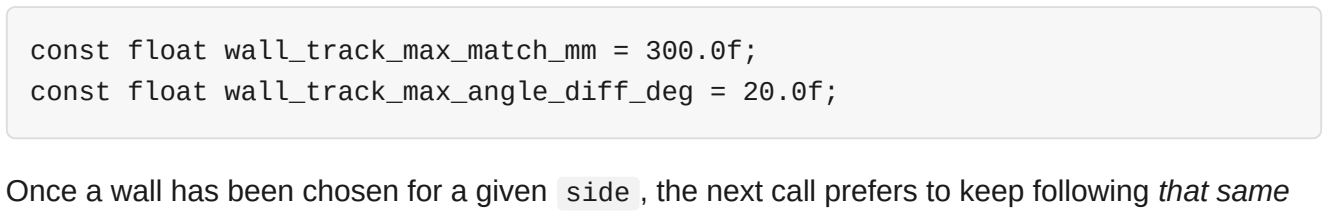
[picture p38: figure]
const float wall_track_max_match_mm = 300.0f; const float wall_track_max_angle_diff_deg = 20.0f;

Once a wall has been chosen for a given side , the next call prefers to keep following that same physical wall (matched by centroid position + orientation) rather than always snapping to whichever segment scores best this frame. This matters because a few degrees of robot rotation can shift the fixed angular window enough that an adjacent wall briefly outscores the wall actually being followed, which previously caused a visible flip mid-turn. If the previously-tracked wall can't be matched within wall_track_max_match_mm / wall_track_max_angle_diff_deg (e.g. it genuinely left the window), the code falls back to the best-scoring candidate and starts tracking that instead — so it still self-recovers.

Tracking state is keyed per- side (a static std::unordered_map<int, WallTrackState> inside Select_Wall ), so front / right / left / behind each track their own wall independently.

### 2.7 Merge a split wall, but not a real corner

const float max_merge_angle_diff_deg = 12.0f;

The chosen wall's points are merged with one other candidate segment (the top-scoring one, or the second-best if the chosen wall already is the top scorer) only if the two segments' independently-fit orientations agree within this threshold. This handles a wall that got split into two segments by a sensor dropout without incorrectly merging two genuinely different walls meeting at a corner (which would fit a meaningless line through neither surface).

### 2.8 Outputs

Slope(side) returns Fit_Line_Orientation() on the final chosen points — a total-least-squares (PCA) line-direction fit, robust to which axis has more variance. Distance_To_Wall(side) returns the perpendicular distance from the robot's origin to that same fitted line (not just the centroid's range, since the centroid can sit off to one side of the perpendicular foot).
Publish_Slope_Used_Angles() records exactly which raw lidar angles fed the result, so the visualization can highlight precisely those points (see below).

### 3. The visualization's wall detector ( postprocess_callback )

This is a separate implementation that scans the entire 360° buffer (not a narrow window around one side) purely to draw the "Lidar Coordinates" debug window. It is not used by
Slope() / Distance_To_Wall() and tuning it does not affect robot behavior — only what you see

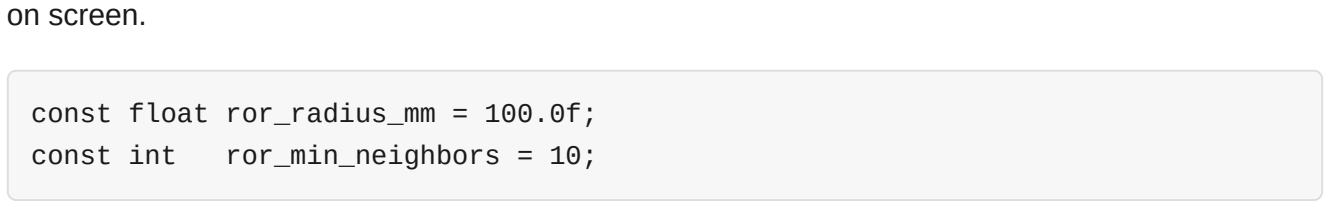
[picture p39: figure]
on screen.; const float ror_radius_mm = 100.0f;; const int; ror_min_neighbors = 10;

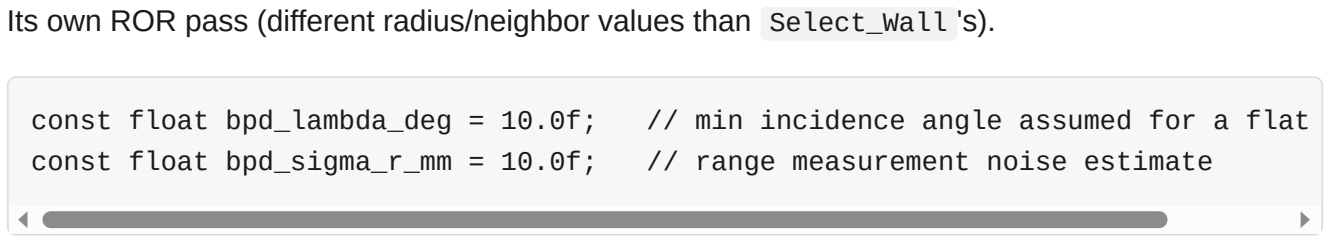
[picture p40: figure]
const float bpd_sigma_r_mm = 10.0f;; // range measurement noise estimate

Its own ROR pass (different radius/neighbor values than Select_Wall 's).

const float bpd_lambda_deg = 10.0f; // min incidence angle assumed for a flat

Uses the Adaptive Breakpoint Detector (Borges & Aldon) instead of a flat gap threshold: the maximum allowed gap between consecutive points ( D_max ) is computed per-point from range and incidence-angle geometry, rather than being a single fixed distance. A smaller bpd_lambda_deg makes D_max larger (more tolerant of gaps, less likely to split) — this was raised from 5° to 10° after a nearby test object failed to split from an adjacent wall (at 5°, a ~450mm-range point had D_max ≈142mm, generous enough to merge a real object into the wall next to it).

Keeps only the max_walls largest segments as "real" walls (everything else is drawn as grey clutter). Also does its own centroid-based color tracking ( wall_tracks ) so the same physical wall keeps the same color across frames instead of flickering when two similarly-sized walls swap size-rank — conceptually similar to Select_Wall 's per-side tracking in §2.6, but keyed by color slot rather than by side , and only used for rendering.

Highlighted-wall distance overlay

Whenever Slope() / Distance_To_Wall() has highlighted a wall (the black-outlined points in the debug view — driven by Publish_Slope_Used_Angles ), the visualization independently computes the perpendicular distance from the origin to that highlighted wall's fitted line, and:

prints it to the terminal: [Highlighted wall] distance=512mm
draws it as text on the canvas, in the same color as the highlighted wall.

This is a display-only echo of the same perpendicular-distance math used in
Distance_To_Wall() — it's recomputed here only so the overlay works even when nothing has called Distance_To_Wall() this frame.

### 4. Mathematical formulas

This section gives the actual math behind each step in §2/§3, using the raw lidar return (angle_deg, range_mm) as the starting point. Points are indexed i = 1..N within whatever set is being processed (a window, a segment, etc.).

### 4.1 Polar → Cartesian conversion

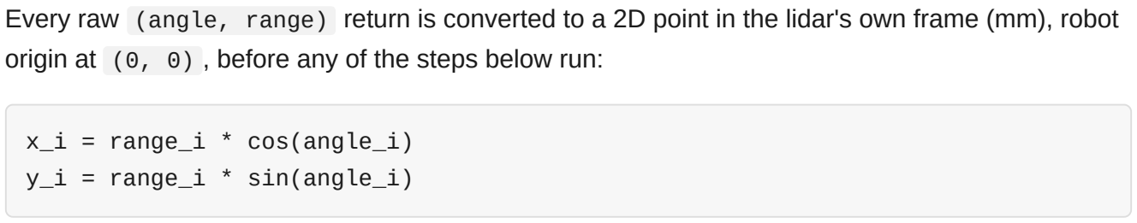
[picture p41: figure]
x_i = range_i * cos(angle_i) y_i = range_i * sin(angle_i)

Every raw (angle, range) return is converted to a 2D point in the lidar's own frame (mm), robot origin at (0, 0) , before any of the steps below run:

### 4.2 Radius Outlier Removal (ROR)

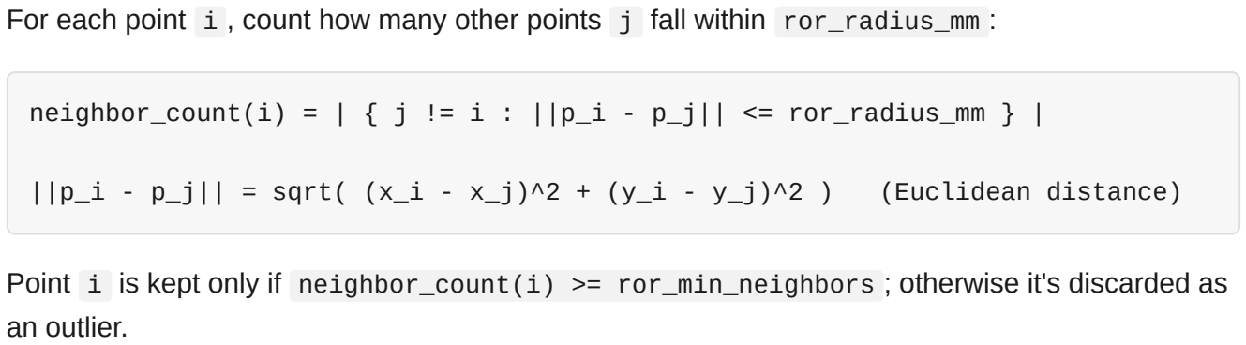
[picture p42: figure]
an outlier.

For each point i , count how many other points j fall within ror_radius_mm :

neighbor_count(i) = | { j != i : ||p_i - p_j|| <= ror_radius_mm } |

||p_i - p_j|| = sqrt( (x_i - x_j)^2 + (y_i - y_j)^2 ) (Euclidean distance)

Point i is kept only if neighbor_count(i) >= ror_min_neighbors ; otherwise it's discarded as

### 4.3 Gap-based segmentation

A new segment starts between consecutive points i-1 and i whenever:

### 4.4 Adaptive Breakpoint Detector (visualization only, Borges & Aldon 2004)

Instead of one fixed gap threshold, the maximum allowed distance between consecutive points

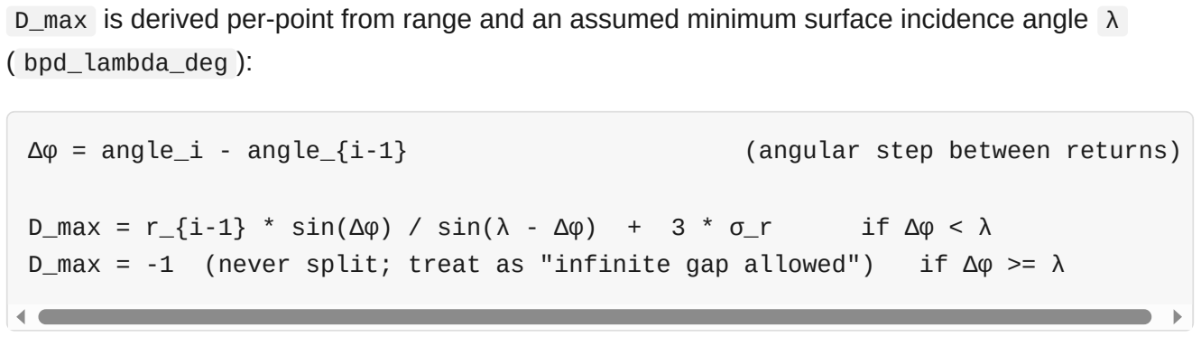
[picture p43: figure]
( bpd_lambda_deg ):; Δφ = angle_i - angle_{i-1}; (angular step between returns)

D_max is derived per-point from range and an assumed minimum surface incidence angle λ

D_max = r_{i-1} * sin(Δφ) / sin(λ - Δφ) + 3 * σ_r | if Δφ < λ
D_max = -1 (never split; treat as "infinite gap allowed") | if Δφ >= λ

where r_{i-1} is the previous point's range and σ_r is bpd_sigma_r_mm (assumed range measurement noise). A new segment starts if ||p_i - p_{i-1}|| > D_max . Intuition: a flat surface seen at a shallow (near-parallel) incidence angle naturally produces bigger point-to-point spacing than one viewed head-on, at the same range — D_max grows accordingly so a real continuous wall isn't falsely split, while λ sets the floor below which any gap at all is treated as a break.

Why a smaller λ makes the detector more tolerant: for fixed Δφ < λ , shrinking λ shrinks (λ
- Δφ) , which shrinks sin(λ - Δφ) (for small angles, sin is roughly linear), which appears in D_max 's denominator — so D_max grows. A larger D_max means more real gaps get "explained away" as an artifact of viewing angle rather than a genuine break in the surface, which is exactly what let a nearby test object merge into the wall next to it at λ = 5° .

### 4.5 Corner splitting (Iterative End-Point Fit / split-and-merge)

For a segment with endpoints p_1 and p_n , every interior point p_k is scored by its perpendicular distance to the straight line p_1 → p_n :

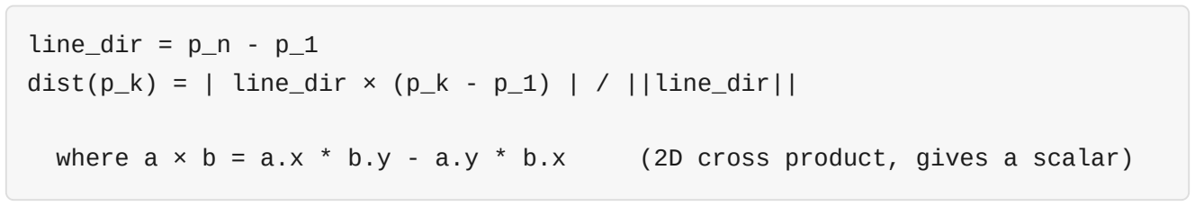
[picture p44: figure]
line_dir = p_n - p_1

dist(p_k) = | line_dir × (p_k - p_1) | / ||line_dir||

where a × b = a.x * b.y - a.y * b.x (2D cross product, gives a scalar)

The point with the largest dist(p_k) is the candidate corner. If max(dist) > corner_split_threshold_mm , the segment is split there (dropping corner_margin_points points on each side of the split index), and the same test is applied recursively to both halves.

### 4.6 Total Least Squares (PCA) line orientation fit

Why not ordinary least squares? Fitting y = mx + b minimizes vertical distance and blows up ( m → ∞ ) for a wall running nearly parallel to the y-axis — which happens constantly here, since a wall can face the robot at any angle. Total Least Squares instead minimizes perpendicular distance to the line, which has no preferred axis and works identically at any orientation. This is exactly what PCA gives you: the line through the centroid along the direction of maximum variance is also the line that minimizes total squared perpendicular distance to it.

Step 1 — center the points. Given the mean (x̄, ȳ) of the segment's N points, form the centered coordinates:

Step 2 — build the 2×2 covariance (scatter) matrix.

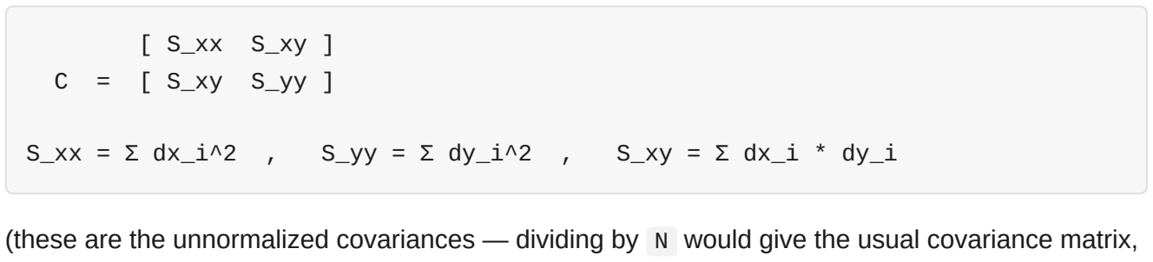
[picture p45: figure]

S_xx = Σ dx_i^2 , | S_yy = Σ dy_i^2 , | S_xy = Σ dx_i * dy_i

(these are the unnormalized covariances — dividing by N would give the usual covariance matrix, but the scale doesn't affect the eigenvectors, so the division is skipped).

Step 3 — find the eigenvector of C with the largest eigenvalue. For a general point cloud, PCA proceeds by eigen-decomposing C . For a symmetric 2×2 matrix this has a closed form instead of needing iterative eigen-solvers:

eigenvalues: λ± = (S_xx + S_yy)/2 ± sqrt( ((S_xx - S_yy)/2)^2 + S_xy^2 )

λ+ (the larger root) is the variance along the wall's direction; λ- is the (ideally small) variance across it — i.e. the noise. The eigenvector belonging to λ+ points along the wall. Rather than solving (C - λ+ I) v = 0 directly for that eigenvector, the code uses the standard double-angle identity for diagonalizing a symmetric 2×2 matrix by rotation: the rotation angle θ that diagonalizes C (equivalently, the direction of its dominant eigenvector) satisfies:

θ = 0.5 * atan2( 2 * S_xy, S_xx - S_yy )

using atan2 (rather than plain atan ) so the correct quadrant is picked up automatically across the full 180° range of possible wall orientations.

θ (converted to degrees) is the line's orientation — the axis of maximum variance through the points, equivalently the total-least-squares best-fit line direction. Because a line and its 180°-rotated reverse describe the same orientation, θ is only meaningful modulo 180° (see the wraparound handling in §4.9).

### 4.7 Line-fit residual (RMS perpendicular error)

Using the same θ from §4.6, the unit normal to the fitted line is n = (-sin θ, cos θ) . Each point's signed perpendicular distance to the line through the centroid is:

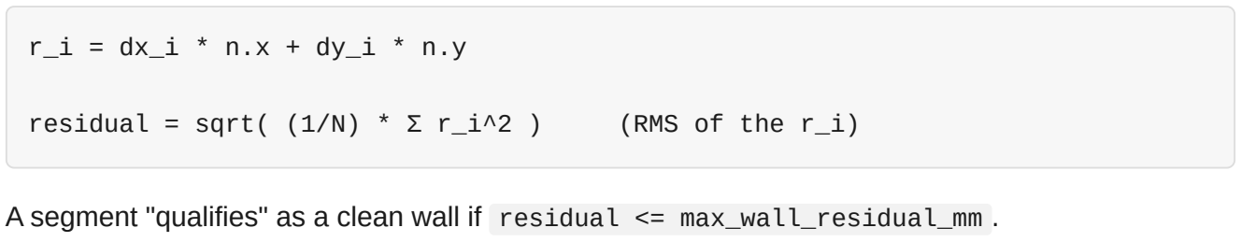
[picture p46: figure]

residual = sqrt( (1/N) * Σ r_i^2 ) (RMS of the r_i)

A segment "qualifies" as a clean wall if residual <= max_wall_residual_mm .

### 4.8 Perpendicular distance from the robot to the wall

Distance_To_Wall() and the visualization's highlighted-wall overlay both compute the distance from the origin (the robot) to the wall's fitted line (not to the wall's centroid point), using the same

unit direction vector dir = (cos θ, sin θ) from §4.6 and the segment's centroid (x̄, ȳ) :

This is the magnitude of the 2D cross product of the centroid position with the line's direction vector — geometrically, the length of the perpendicular dropped from the origin onto the infinite line through the centroid along dir .

### 4.9 Wall-identity matching (tracking)

Both Select_Wall 's per-side tracking (§2.6) and the visualization's color tracking match a candidate segment c against a previously-tracked wall t using two independent criteria that

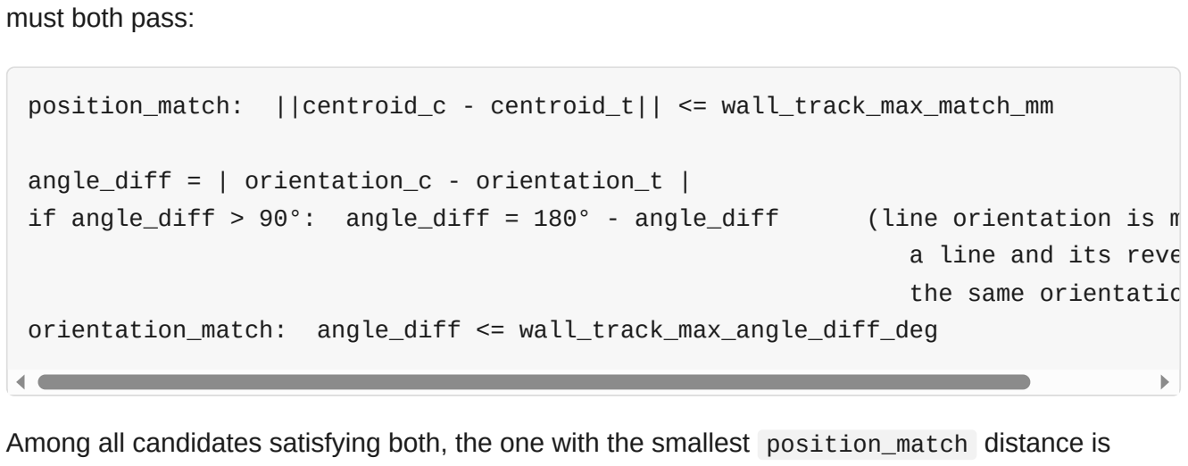
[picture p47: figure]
must both pass:; a line and its reve the same orientatio orientation_match: angle_diff <= wall_track_max_angle_diff_deg

position_match: ||centroid_c - centroid_t|| <= wall_track_max_match_mm

angle_diff = | orientation_c - orientation_t |
if angle_diff > 90°: angle_diff = 180° - angle_diff | (line orientation is m

Among all candidates satisfying both, the one with the smallest position_match distance is chosen as the continuation of the tracked wall.

### 4.10 Angle classification (side labeling)

Given a wall's centroid, its angle from the robot is atan2(ȳ, x̄) (normalized to [0°, 360°) ). To classify which side it's nearest to, the angular difference to each reference angle ( front=270°, right=0°, left=180°, behind=90° ) is computed with wraparound handled the same way as

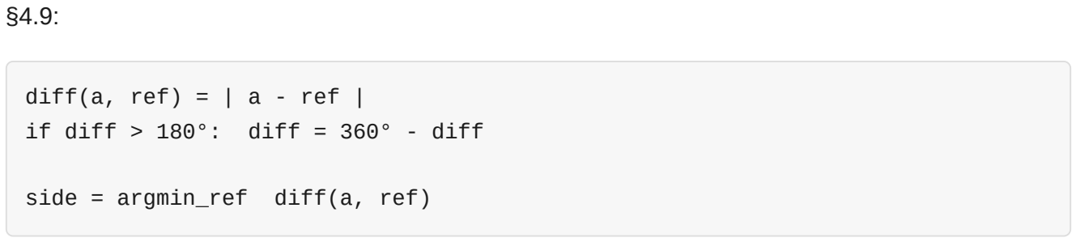
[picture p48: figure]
diff(a, ref) = | a - ref | if diff > 180°: diff = 360° - diff; side = argmin_ref diff(a, ref)

### 5. Quick reference: constants likely to need re-tuning

Constant | Location | Current value | Purpose
middle_point per side | Select_Wall switch | front=270, right=0, left=180, behind=90 | Lidar-mount-specific angle offset — re-derive if the lidar is replaced/reseated
point | Select_Wall | 70° | Angular window width per side
min_range_mm | Select_Wall | 150mm | Excludes robot's own chassis
ror_radius_mm / ror_min_neighbors | Select_Wall | 300mm / 3 | Outlier rejection
gap_threshold_mm | Select_Wall | 60mm | Gap-based wall segmentation
corner_split_threshold_mm | Select_Wall | 40mm | Corner detection sensitivity
min_wall_points | Select_Wall | 6 | Minimum points to be considered a wall
max_wall_residual_mm | Select_Wall | 15mm | Max noise for a wall to "qualify"
min_wall_extent_mm | Select_Wall | 200mm | Minimum physical
size (excludes

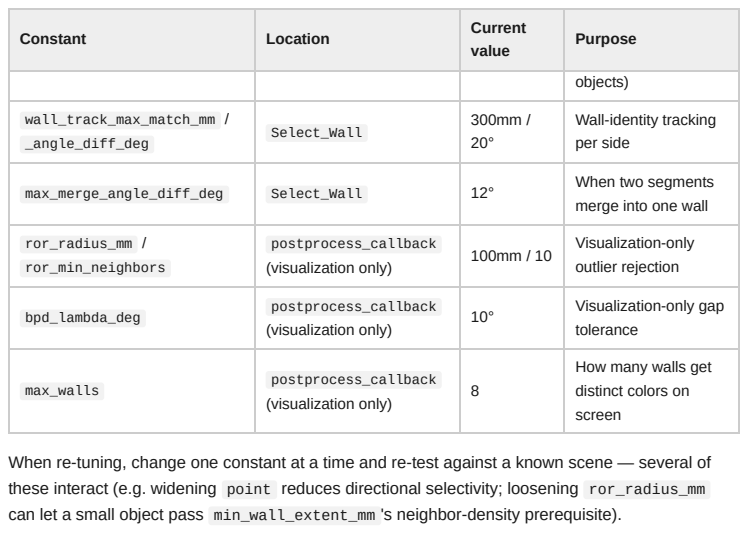
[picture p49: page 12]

Constant | Location | Current value | Purpose

objects)

wall_track_max_match_mm / _angle_diff_deg | Select_Wall | 300mm / 20° | Wall-identity tracking per side

max_merge_angle_diff_deg | Select_Wall | 12° | When two segments merge into one wall

ror_radius_mm / ror_min_neighbors | postprocess_callback (visualization only) | 100mm / 10 | Visualization-only outlier rejection

bpd_lambda_deg | postprocess_callback (visualization only) | 10° | Visualization-only gap tolerance

max_walls | postprocess_callback (visualization only) | 8 | How many walls get distinct colors on screen

When re-tuning, change one constant at a time and re-test against a known scene — several of
these interact (e.g. widening point reduces directional selectivity; loosening ror_radius_mm
can let a small object pass min_wall_extent_mm 's neighbor-density prerequisite).

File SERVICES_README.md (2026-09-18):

# WRO Future Engineers - Startup Services

Two systemd services are installed on this Raspberry Pi. They both use the
same hardware (camera / lidar / serial), so only **one** of them should be
running at a time. They are configured with `Conflicts=` so starting one
will automatically stop the other.

1. **`object_detection.service`**
   Runs:
   ```
   /home/maker/WRO_Future_Engineers_Queretaro_CSS/src/cpp/object_detection_original_h10/build/h10_original/object_detection \
     --net /home/maker/WRO_Future_Engineers_Queretaro_CSS/src/HailoModels/roboflow_yolov8n_wro_h10.hef \
     --input rpi --no-display
   ```

2. **`my_lidar_app.service`**
   Runs:
   ```
   /home/maker/WRO_Future_Engineers_Queretaro_CSS/src/ondevice/my_lidar_app
   ```

Service unit files live in `/etc/systemd/system/`.

## Choosing which one runs on boot

Only "enable" the one you want to auto-start. Example, to boot into
`object_detection.service`:

```sh
sudo systemctl disable my_lidar_app.service
sudo systemctl enable object_detection.service
```

Or to boot into `my_lidar_app.service` instead:

```sh
sudo systemctl disable object_detection.service
sudo systemctl enable my_lidar_app.service
```

You can also leave both disabled if you don't want anything to auto-start,
and just start one manually when needed (see below).

## Basic commands

Replace `SERVICE` with either `object_detection.service` or `my_lidar_app.service`.

| Action | Command |
|---|---|
| Start now (without enabling on boot) | `sudo systemctl start SERVICE` |
| Stop | `sudo systemctl stop SERVICE` |
| Restart | `sudo systemctl restart SERVICE` |
| Enable on boot (auto-starts every startup) | `sudo systemctl enable SERVICE` |
| Enable AND start immediately | `sudo systemctl enable --now SERVICE` |
| Disable on boot (won't auto-start anymore) | `sudo systemctl disable SERVICE` |
| Disable AND stop immediately | `sudo systemctl disable --now SERVICE` |
| Check current status (running/stopped, recent log lines) | `sudo systemctl status SERVICE` |
| Check whether it's enabled on boot | `systemctl is-enabled SERVICE` |
| Check whether it's currently running | `systemctl is-active SERVICE` |

## Viewing logs

```sh
# Follow logs live (Ctrl+C to stop watching, does NOT stop the service)
sudo journalctl -u SERVICE -f

# Show last 50 lines
sudo journalctl -u SERVICE -n 50

# Show logs since last boot
sudo journalctl -u SERVICE -b
```

## Interrupting / stopping mid-run

- If you ran the binary directly in a terminal (not via systemd), press
  **Ctrl+C**. `object_detection` has a `SIGINT` handler for graceful shutdown.
- If it's running as a systemd service (in the background, no terminal),
  Ctrl+C does nothing because there's no attached terminal. Use:
  ```sh
  sudo systemctl stop SERVICE
  ```
  Note: `systemctl stop` sends `SIGTERM` by default, not `SIGINT`. If you need
  the exact same graceful-shutdown behavior as Ctrl+C, add a line
  `KillSignal=SIGINT` under `[Service]` in the `.service` file and run
  `sudo systemctl daemon-reload`.

## Editing a service file

1. Edit the file with sudo, e.g.:
   ```sh
   sudo nano /etc/systemd/system/object_detection.service
   ```
2. Reload systemd so it picks up the change:
   ```sh
   sudo systemctl daemon-reload
   ```
3. Restart the service to apply changes:
   ```sh
   sudo systemctl restart object_detection.service
   ```

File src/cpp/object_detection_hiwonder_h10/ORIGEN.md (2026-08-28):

# Procedencia de la variante

La base se copió el 2026-08-23 desde el estado de trabajo actual de:

```text
maker@Hailo10Wifi:
/home/maker/WRO_Future_Engineers_Queretaro_CSS/software_h10/cpp/object_detection_original_h10
```

Repositorio remoto:
`https://github.com/alex309-duarte/WRO_Future_Engineers_Queretaro_CSS.git`.
HEAD observado: `dea835645dc9deaecab655e65a95ad5601f5bd32` (`Open Challenge
improvements`).

El árbol de origen ya tenía cambios locales sin confirmar en
`object_detection.cpp`, `Oradar_S2L.*`, `common_var.h` y `spike.*`. La variante
parte deliberadamente de esos archivos de trabajo porque son los que producen
el ejecutable que usa el usuario. No se modificó ni limpió el origen.

La biblioteca Hiwonder se tomó del repositorio canónico de Windows:

```text
C:\Users\jesus\Documents\Jetson_cerebro\robotica\hiwonder_brick
```

`toolbox.cpp/.hpp` se copió a la variante para hacer observable
`terminating_main` desde el hilo de cámara y cerrar las colas al recibir
`Ctrl+C`, sin alterar el archivo común ni el programa original.

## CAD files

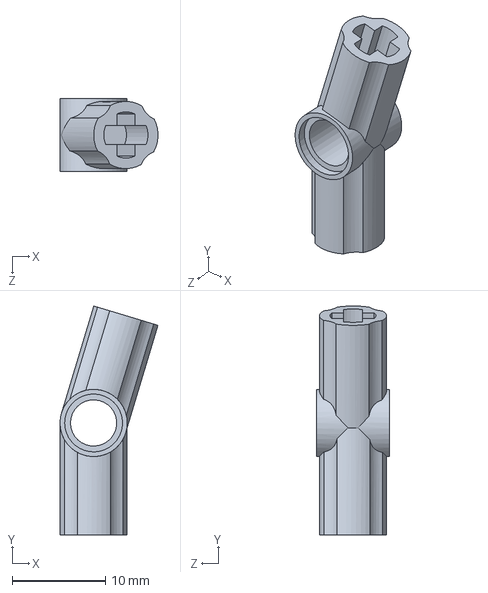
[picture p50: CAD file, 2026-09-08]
models/cad/Final_assembly/axle hole angle.SLDPRT
10.5 x 24.5 x 7.87 mm

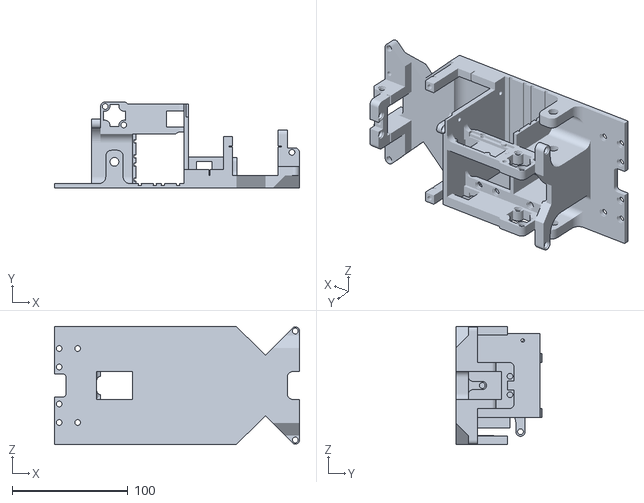
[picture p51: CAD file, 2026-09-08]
models/cad/Stl/Base.STL
212.0 x 74.7 x 102.2

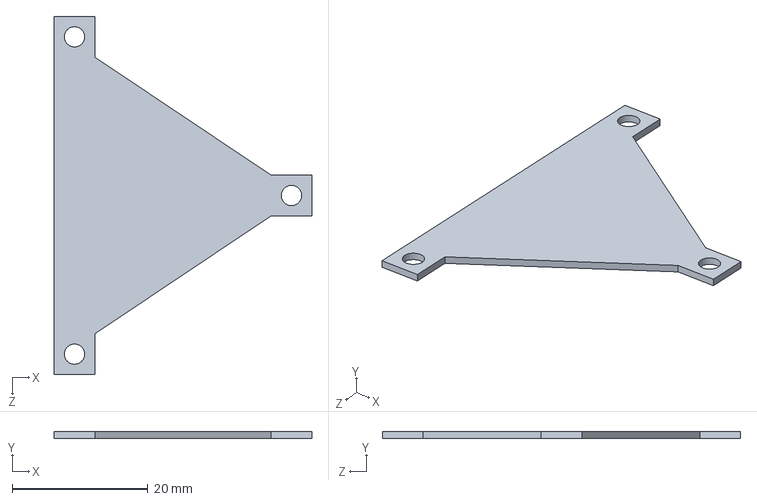
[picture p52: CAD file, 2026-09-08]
models/cad/Final_assembly/lidar_base.SLDPRT
38.0 x 1.00 x 52.8 mm

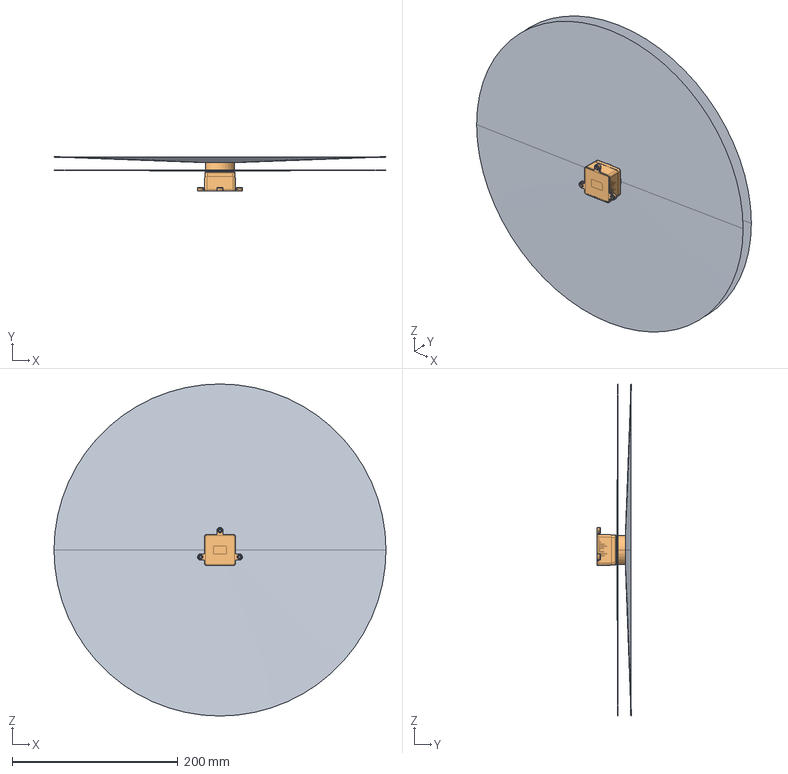
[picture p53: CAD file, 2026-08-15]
models/cad/Iterations/New_design/MS200k_(SR)X3_20240709.stp
400.0 x 41.0 x 400.0 mm

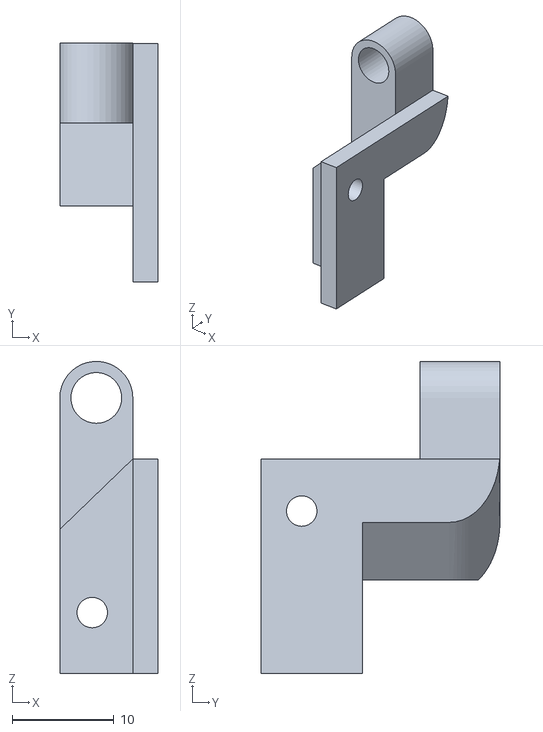
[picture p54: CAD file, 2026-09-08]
models/cad/Stl/ackerman_wheel_join.STL
9.70 x 23.5 x 30.7

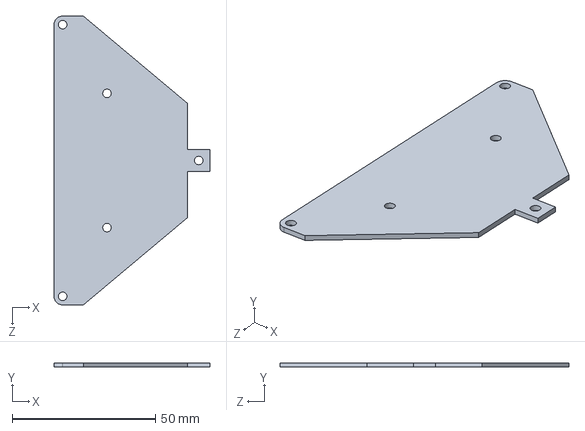
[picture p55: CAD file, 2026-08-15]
models/cad/Iterations/New_design/soporte lidar new.SLDPRT
54.4 x 1.50 x 100.7 mm

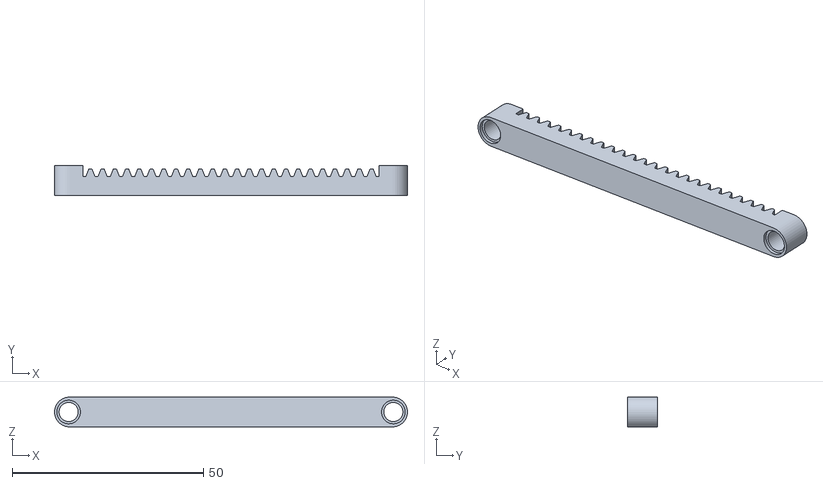
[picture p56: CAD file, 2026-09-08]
models/cad/Stl/rack.STL
92.4 x 7.87 x 7.80

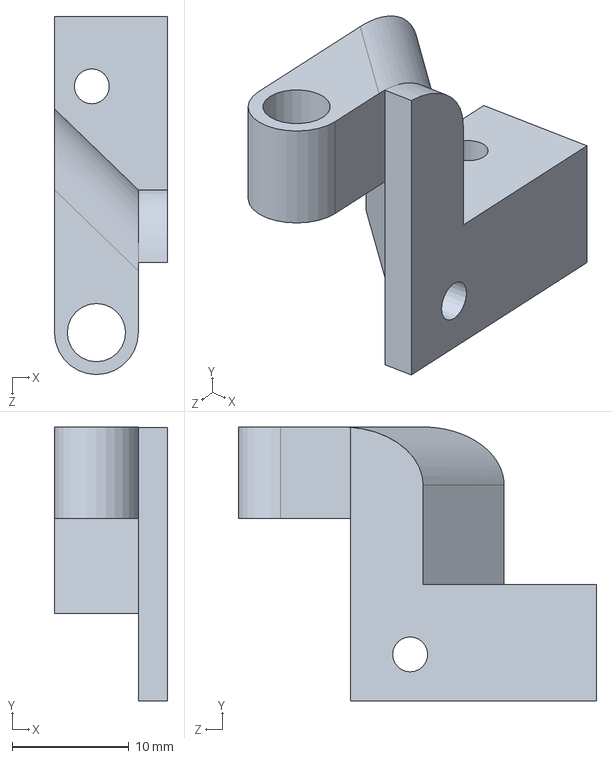
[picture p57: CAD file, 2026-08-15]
models/cad/Iterations/New_design/Ackerman 2.SLDPRT
9.70 x 23.5 x 30.7 mm

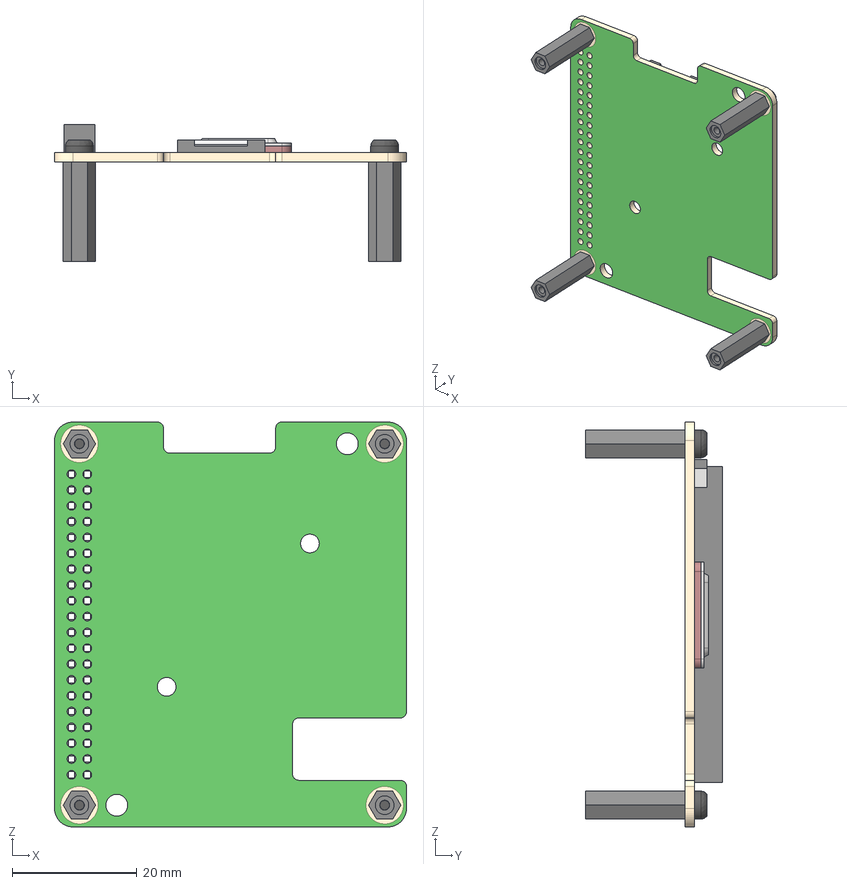
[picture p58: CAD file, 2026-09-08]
models/cad/Final_assembly/RPiAIHATPlus.stp
56.5 x 22.1 x 65.0 mm
RPiAIHATPlusBoard
RPiAIHATPlusLeg x 4
RPiAIHATPlusScrew x 4

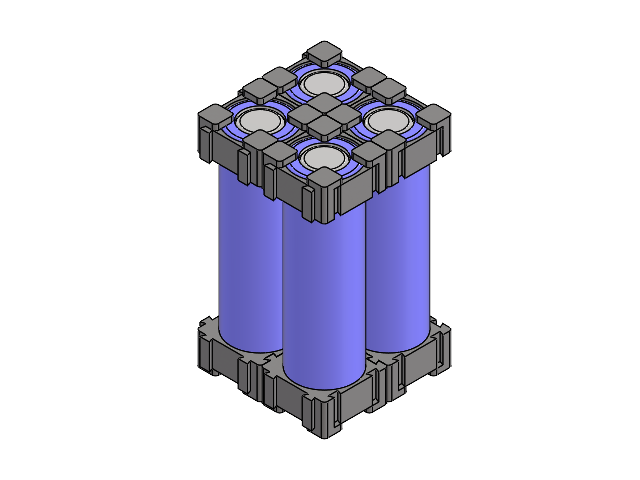
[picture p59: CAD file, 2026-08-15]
models/cad/Iterations/New_design/pilas.SLDASM
1P Holder x 8

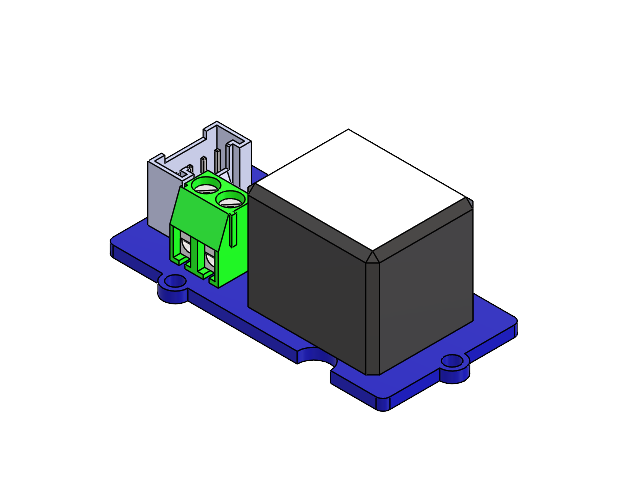
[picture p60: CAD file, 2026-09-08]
models/cad/Final_assembly/Grove relay v1.2 (1).SLDASM
PCB grove 20x40
Relais HLS8L-DC3V-S-C
Connecteur Grove (droit)
Bornier 2ct

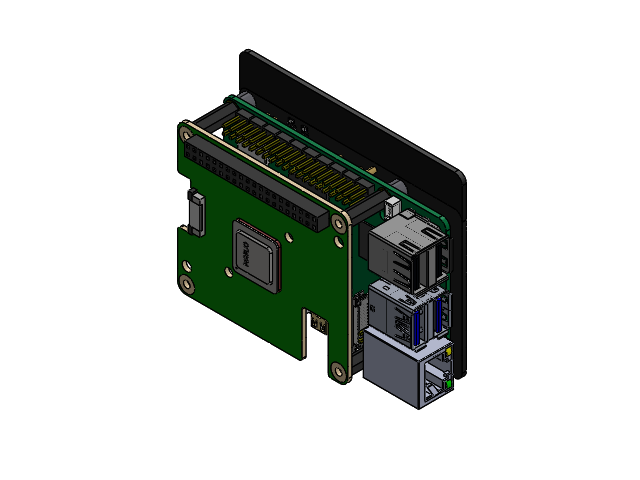
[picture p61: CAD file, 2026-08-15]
models/cad/Iterations/New_design/raspberry.SLDASM
SOLID-1355.step
SOLID-1356.step
SOLID-1357.step
SOLID-1358.step
SOLID-1359.step
SOLID-1360.step
SOLID-1361.step
SOLID-1362.step
SOLID-1363.step
SOLID-1364.step
SOLID-1365.step
SOLID-1366.step
SOLID-1367.step
SOLID-1368.step
SOLID-1369.step
SOLID-1370.step
SOLID-1371.step
SOLID-1372.step
SOLID-1373.step
SOLID-1374.step
SOLID-1375.step
SOLID-1376.step
SOLID-1377.step
SOLID-1378.step
SOLID-1379.step
SOLID-1380.step
SOLID-1381.step
SOLID-1382.step
SOLID-1383.step
SOLID-1384.step
SOLID-1385.step
SOLID-1386.step
SOLID-1387.step
SOLID-1388.step
SOLID-1389.step
SOLID-1390.step
SOLID-1391.step
SOLID-1392.step
SOLID-1393.step
SOLID-1394.step
GPIO-HEADER.step
GROUND-1426.step
GROUND-1427.step
GROUND-1428.step
GROUND-1429.step
RAM.step
CPU.step
CHIP-1454.step
CHIP-1455.step
CHIP-1456.step
CHIP-1457.step
SOLID-1465.step
SOLID-1466.step
SOLID-1467.step
SOLID-1468.step
SOLID-1469.step
SOLID-1470.step
SOLID-1471.step
SOLID-1472.step
SOLID-1473.step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

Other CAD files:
models/cad/Iterations/New_design/Grove relay v1.2 (1).SLDASM
models/cad/Final_assembly/raspberry.SLDASM
models/cad/Final_assembly/pilas.SLDASM
models/cad/Final_assembly/Base.SLDPRT
models/cad/Final_assembly/MS200k_(SR)X3_20240709.stp
models/cad/Stl/lidar_support.STL
models/cad/Final_assembly/18650.SLDPRT
models/cad/Final_assembly/1P Holder.SLDPRT
models/cad/Final_assembly/32270Technic Gear 12 Tooth Double Bevel v1.SLDPRT
models/cad/Final_assembly/32270Technic Gear 12 Tooth Double Bevel v1.step
models/cad/Final_assembly/Ackerman 2.SLDPRT
models/cad/Final_assembly/Bornier 2ct.SLDPRT
models/cad/Final_assembly/Camera Moudule 3 v8.SLDASM
models/cad/Final_assembly/Camera Moudule 3 v8.step
models/cad/Final_assembly/Connecteur Grove (droit).SLDPRT
models/cad/Final_assembly/Cremallera.SLDPRT
models/cad/Final_assembly/Geekworm X1200 UPS HAT.SLDPRT
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

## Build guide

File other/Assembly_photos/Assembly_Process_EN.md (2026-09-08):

# Robot assembly process

**WRO Future Engineers · Queretaro CSS**

26 selected photos, in chronological build order (based on the EXIF capture date/time). Near-duplicate or non-relevant photos were left out.

---

## Before starting you should Print the pieces, STL files are available in STL folder, for this robot the chasis was printed using black PTG using Creality K1C 

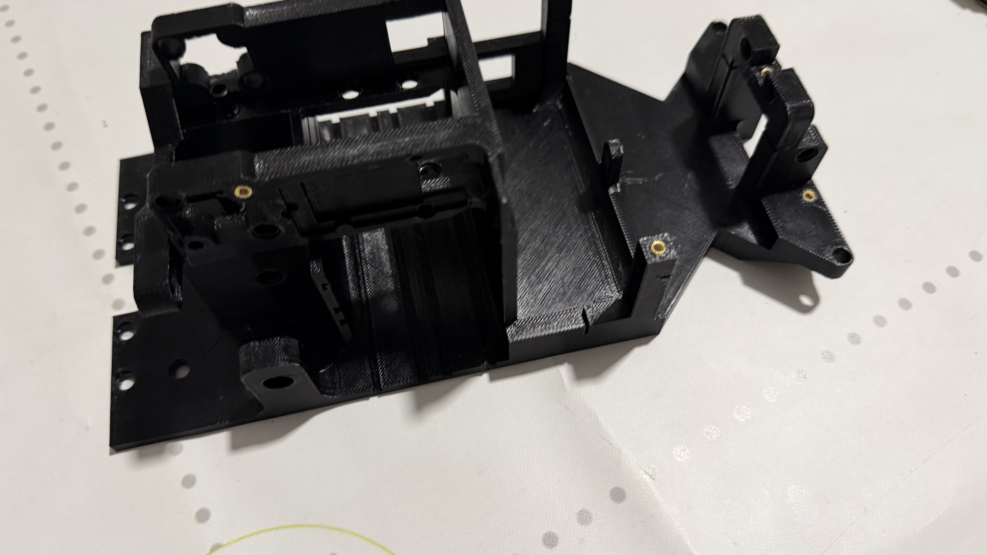
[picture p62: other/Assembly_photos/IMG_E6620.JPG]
3D-printed chassis


---

## Put the heat-set inserts

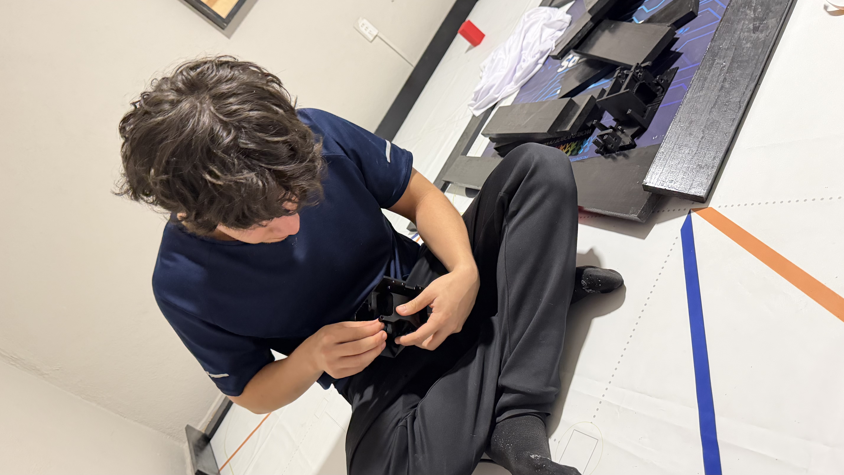
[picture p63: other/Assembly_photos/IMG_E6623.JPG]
Starting the chassis assembly


---

## Step 1 of 24 — Shafts and drive gear

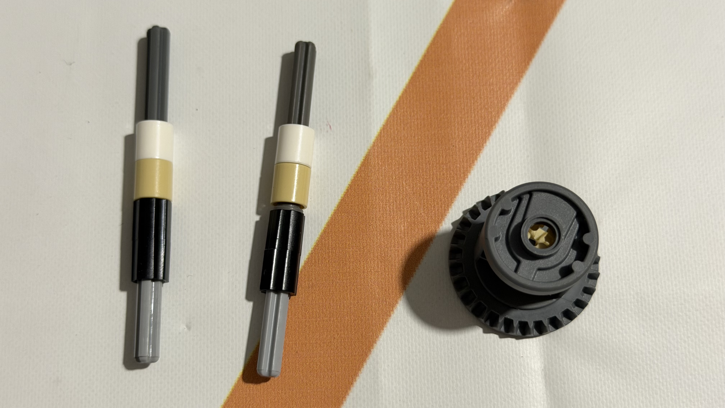
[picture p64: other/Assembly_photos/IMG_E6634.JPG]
Shafts and drive gear


Lego shafts and the drive gear/pulley, loose parts before being mounted inside the gearbox.

---

## Step 2 of 24 — First gear installed

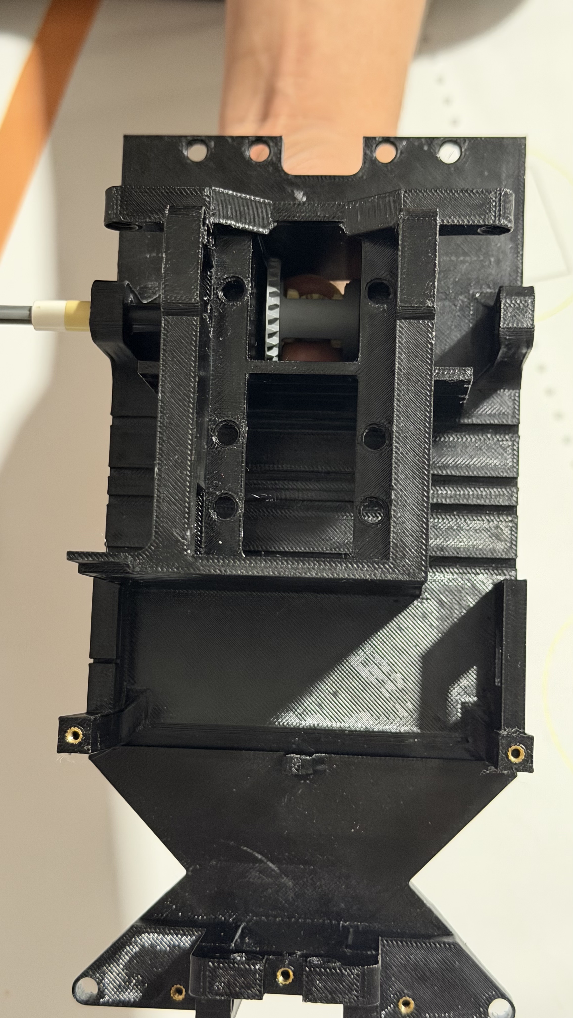
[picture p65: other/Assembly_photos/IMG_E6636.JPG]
First gear installed


Gearbox with the first gear and its shaft already installed inside the chassis.

---

## Step 3 of 24 — Installing traction motor

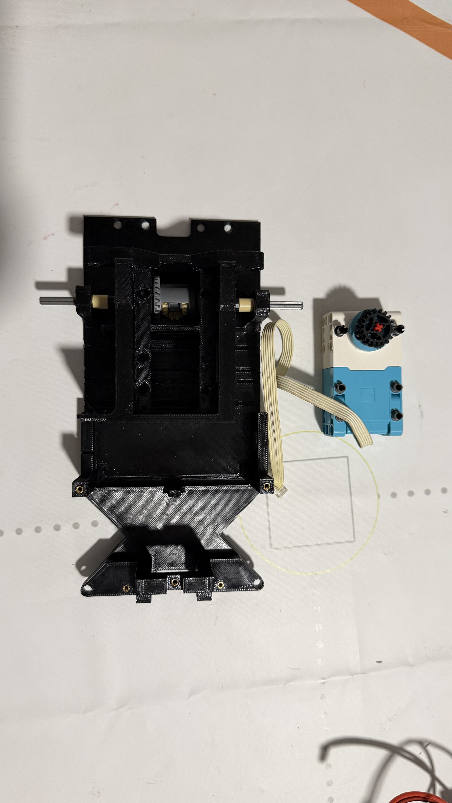
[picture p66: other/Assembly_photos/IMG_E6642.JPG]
Installing the steering servo


The traction motor (blue) being placed at the front of the chassis.

---

## Step 4 of 24 — Side view with traction motor installed

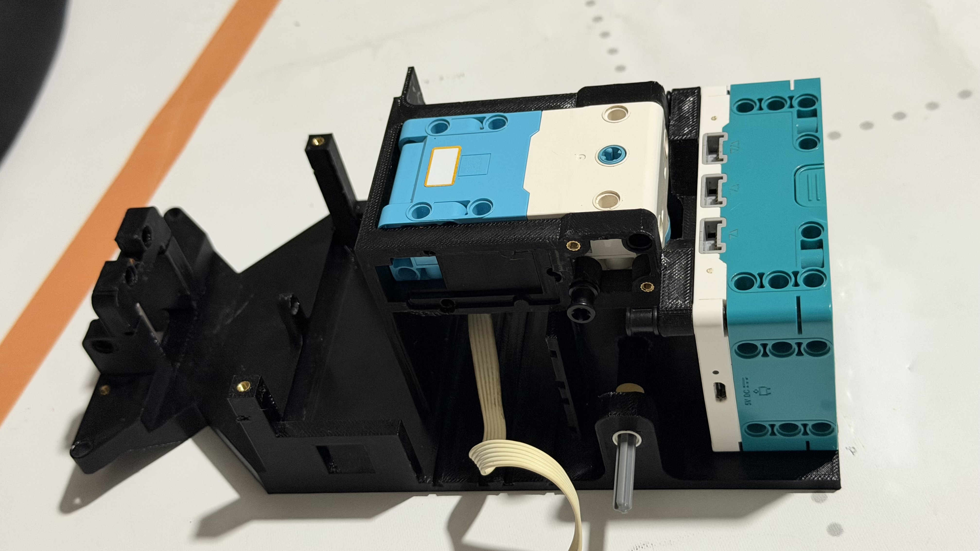
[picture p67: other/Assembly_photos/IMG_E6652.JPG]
Side view with steering installed


Side of the chassis showing the traction motor and its wiring already integrated.

---

## Step 5 of 24 — The robot's brain integrated

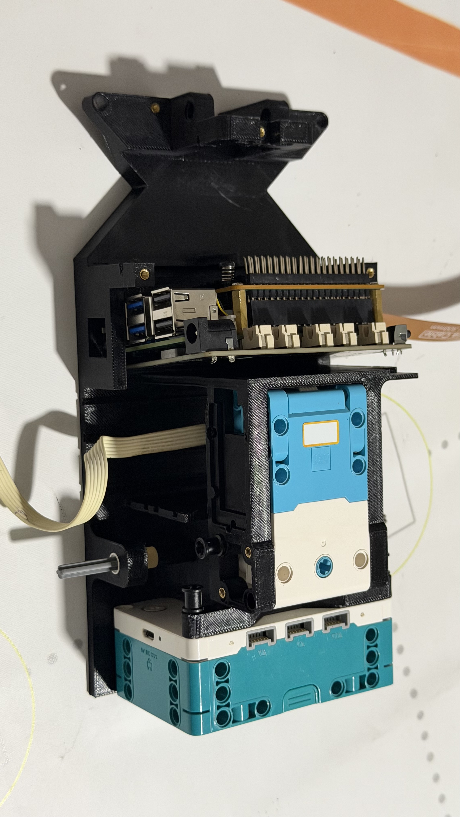
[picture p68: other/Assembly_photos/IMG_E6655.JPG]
The robot's brain integrated


The Raspberry Pi with the AI HAT stacked on the chassis, with the flex cables already connected: the compute system integrated into the structure.

---

## Step 6 of 24 — Securing the compute board

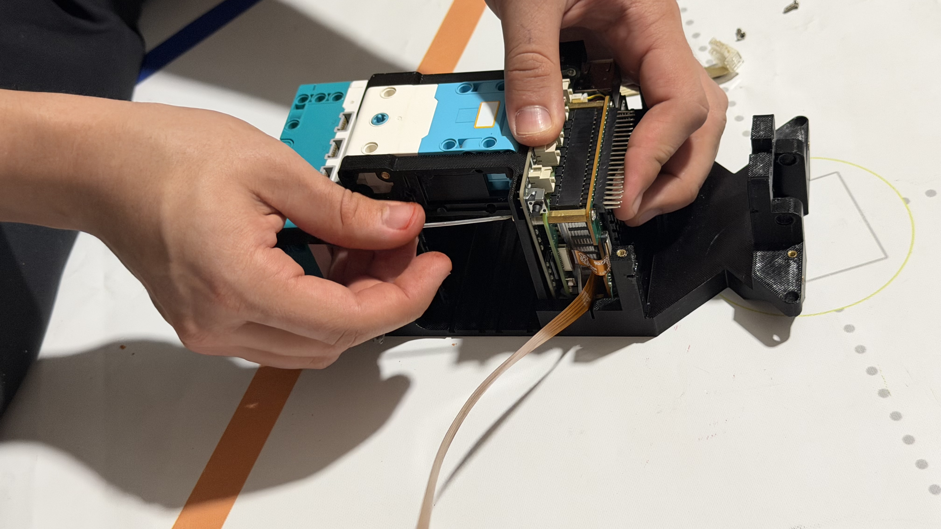
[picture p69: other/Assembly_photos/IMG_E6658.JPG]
Securing the compute board


Adjusting and centering the Raspberry Pi/HAT board on the chassis to screw it in place.

---

## Step 7 of 24 — Grove modules ready

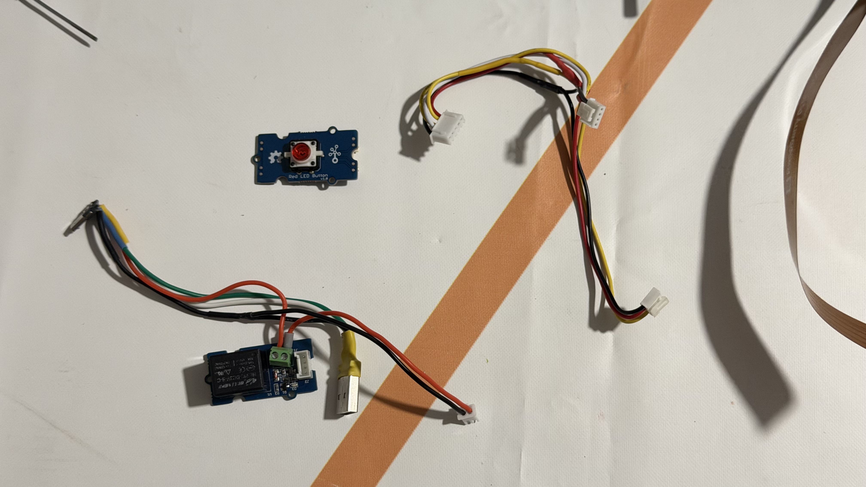
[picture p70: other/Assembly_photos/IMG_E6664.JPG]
Grove modules ready


Grove LED-button module and relay module, with their wiring, ready to be installed on the chassis.

---

## Step 8 of 24 — Drivetrain from below

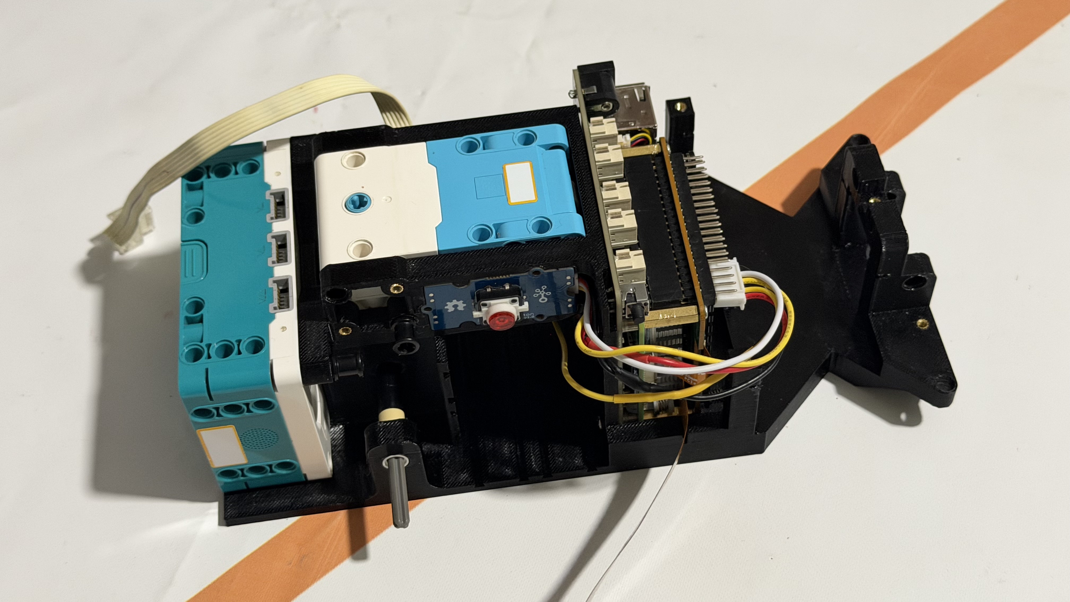
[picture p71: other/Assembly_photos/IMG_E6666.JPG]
Drivetrain from below


Top view of the chassis showing the drive motor, gears, and wiring already integrated.

---

## Step 9 of 24 — Wiring the motors

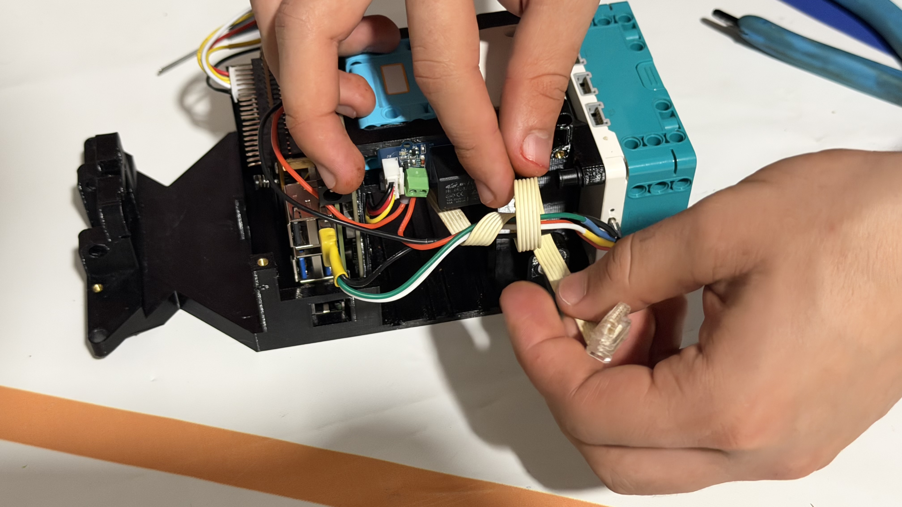
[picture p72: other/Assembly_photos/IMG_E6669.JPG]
Wiring the motors


Connecting the motor and servo cables to the driver's connectors inside the chassis.

---

## Step 10 of 24 — Battery installed

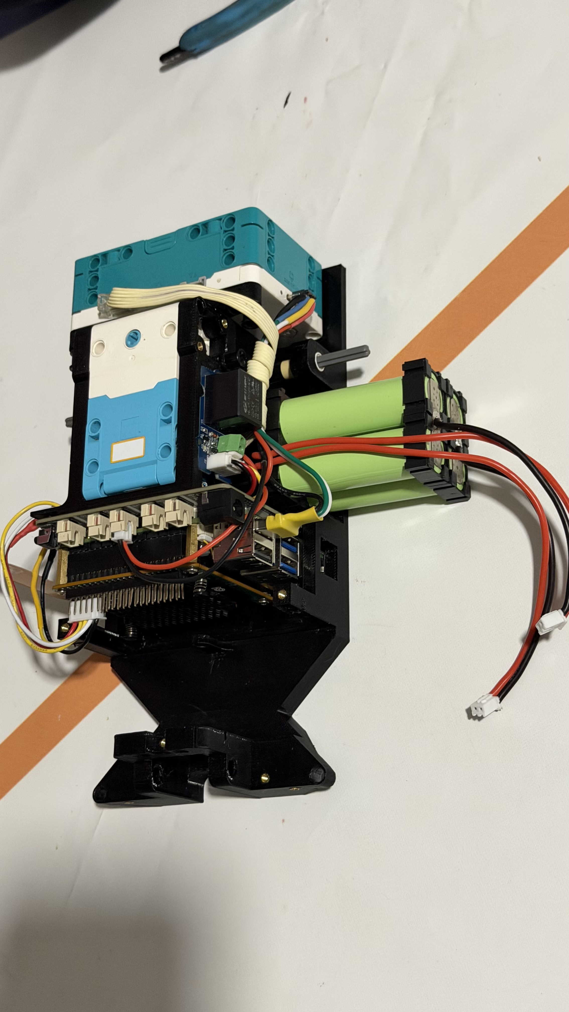
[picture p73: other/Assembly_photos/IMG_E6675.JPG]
Battery installed


Chassis standing upright with the 18650 battery pack now mounted at the rear.

---

## Step 11 of 24 — Front stering bracket parts

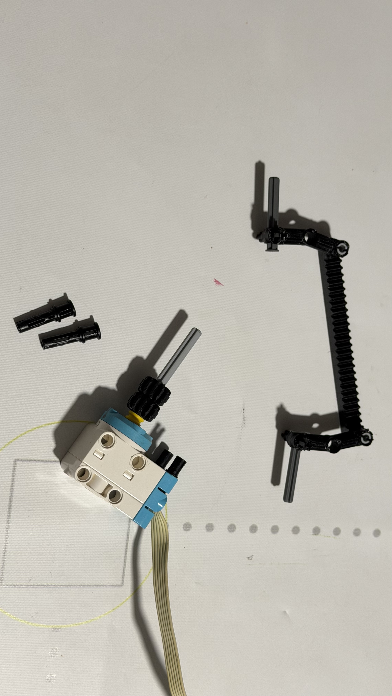
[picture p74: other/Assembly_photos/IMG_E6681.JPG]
Rear bracket parts


Front steering arm/bracket and hardware, loose before being mounted into the rear axle.

---

## Step 12 of 24 — Installing the front bracket

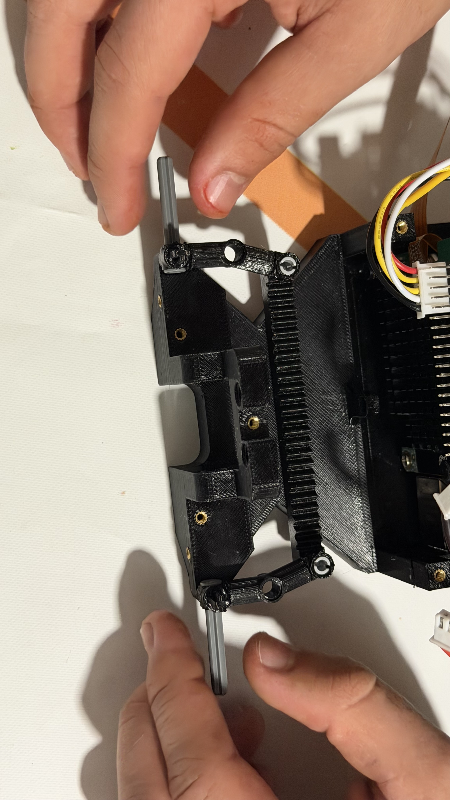
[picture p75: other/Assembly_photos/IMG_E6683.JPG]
Installing the rear bracket


Mounting the front arm/bracket into the chassis's steering axle.

---

## Step 13 of 24 — Front axle assembled

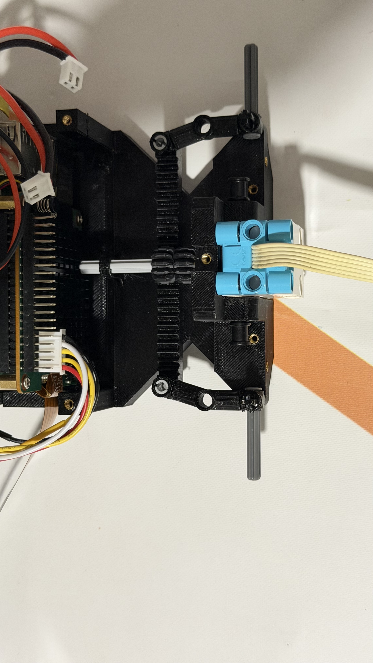
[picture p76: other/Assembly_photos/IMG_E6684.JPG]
Rear axle assembled


Front axle with the steering arm and blue connectors already mounted, seen from behind.

---

## Step 14 of 24 — Front axle ready for wheels

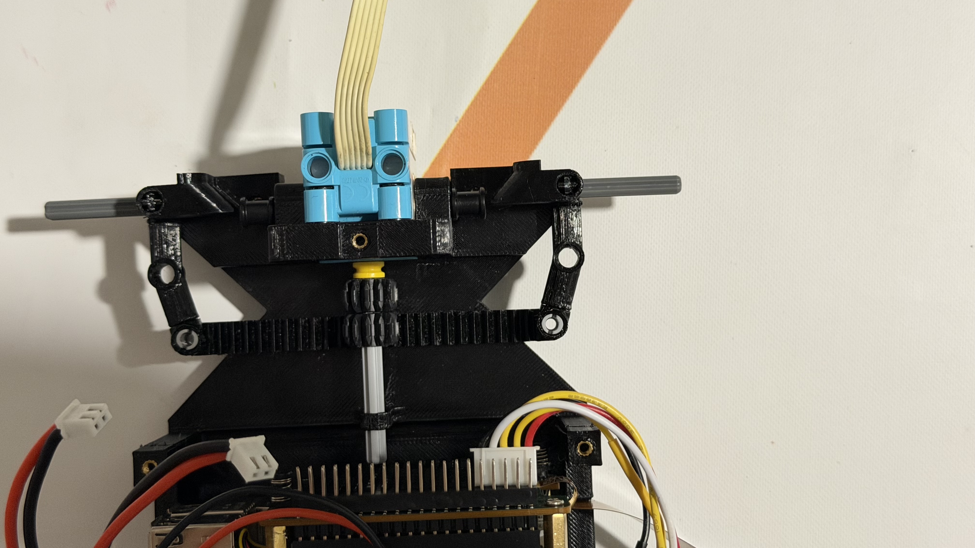
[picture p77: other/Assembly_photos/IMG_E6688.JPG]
Front axle ready for wheels


Front axle with the steering arm already installed, ready to receive the wheels.

---

## Step 15 of 24 — Lidar mount

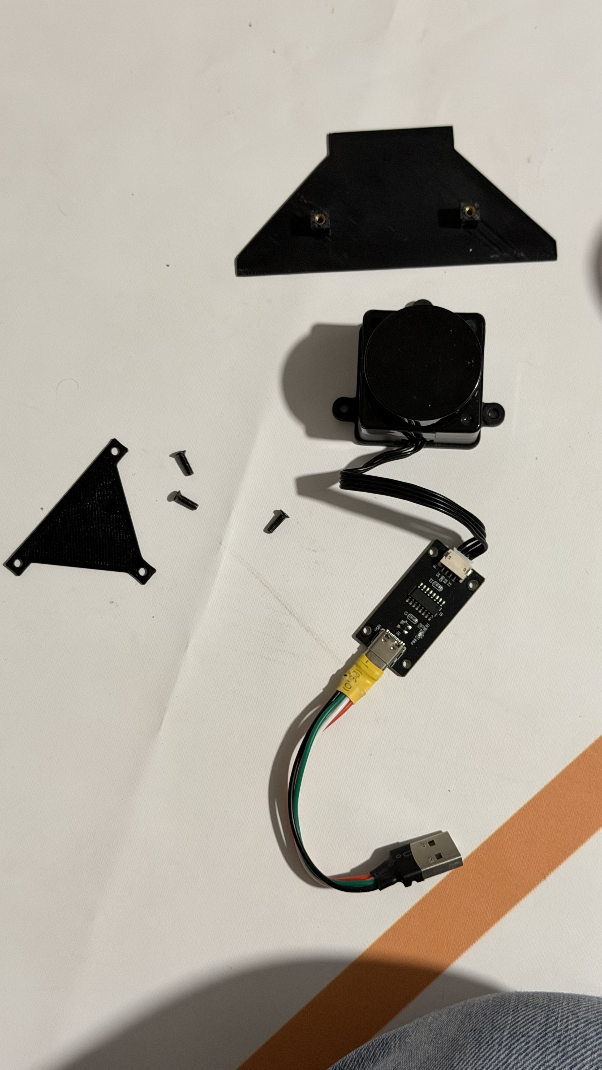
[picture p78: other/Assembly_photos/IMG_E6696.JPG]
Camera mount and motor


---

## Step 16 of 24 — Chassis nearly complete

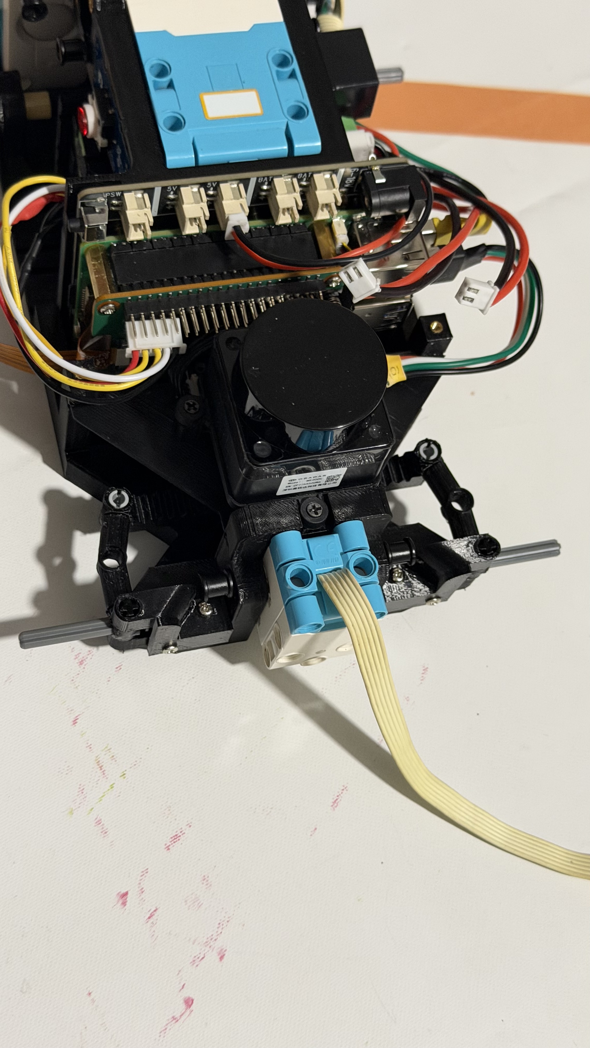
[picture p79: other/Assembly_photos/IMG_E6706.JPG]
Chassis nearly complete


The chassis standing upright, showing all the main electronics already integrated vertically.

---

## Step 17 of 24 — Full assembly without wheels

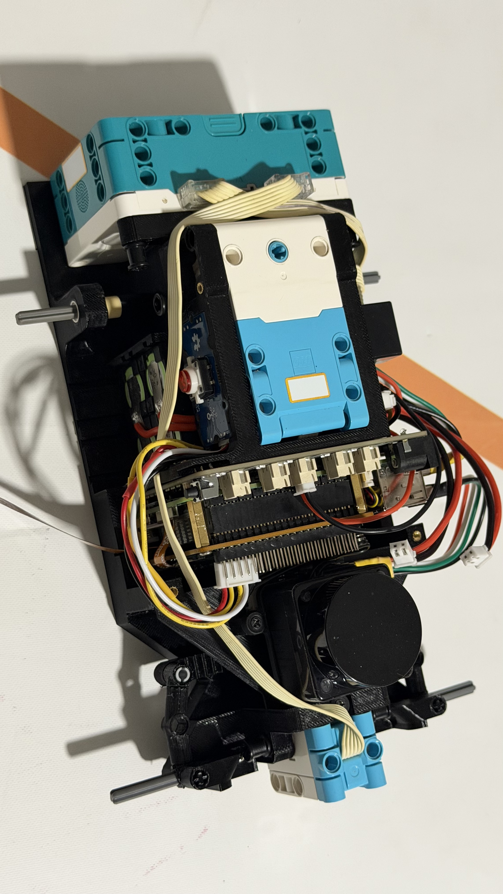
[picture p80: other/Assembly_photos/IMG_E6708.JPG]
Full assembly without wheels


Top view of the fully assembled chassis, still without the wheels installed.

---

## Step 18 of 24 — Final wiring adjustment

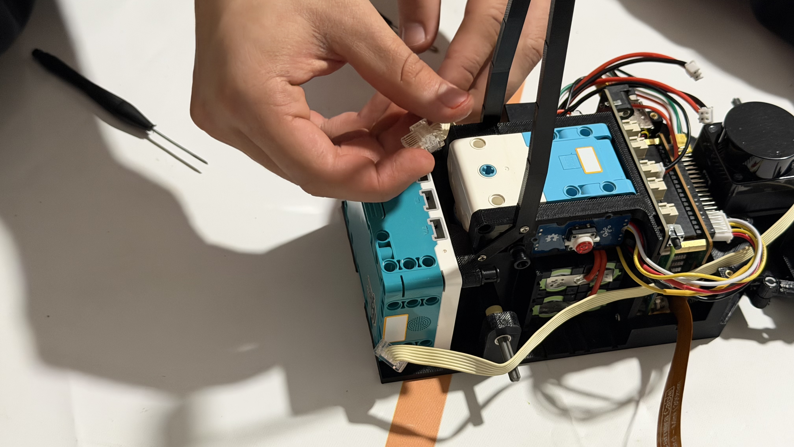
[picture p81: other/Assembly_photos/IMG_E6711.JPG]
Final wiring adjustment


Adjusting a final cable with pliers before proceeding to install the wheels.

---

## Step 19 of 24 — Full wiring visible

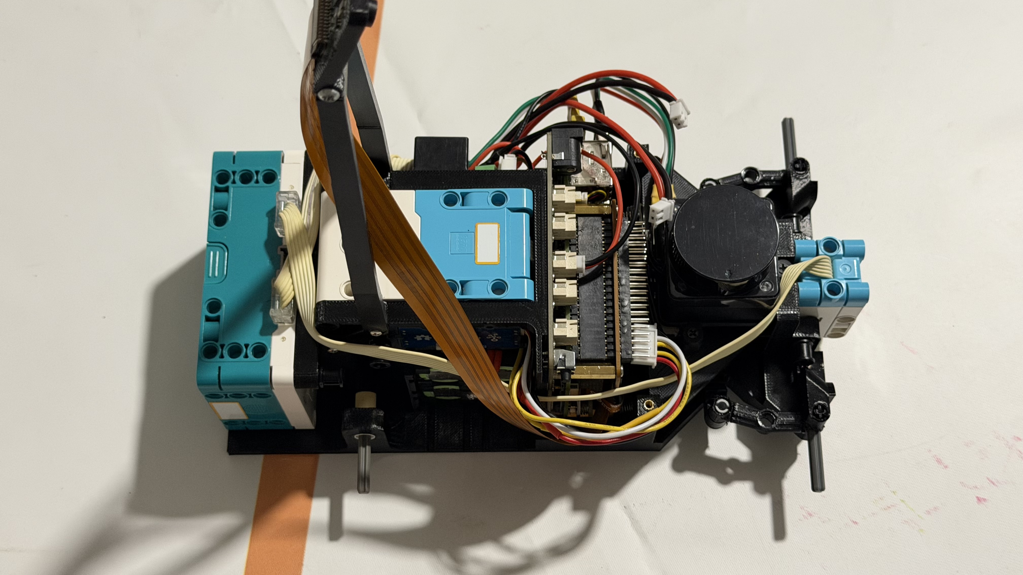
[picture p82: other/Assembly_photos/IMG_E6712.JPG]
Full wiring visible


Chassis lying on its side, showing the complete wiring running through the whole structure.

---

## Step 20 of 24 — Wheels ready to mount

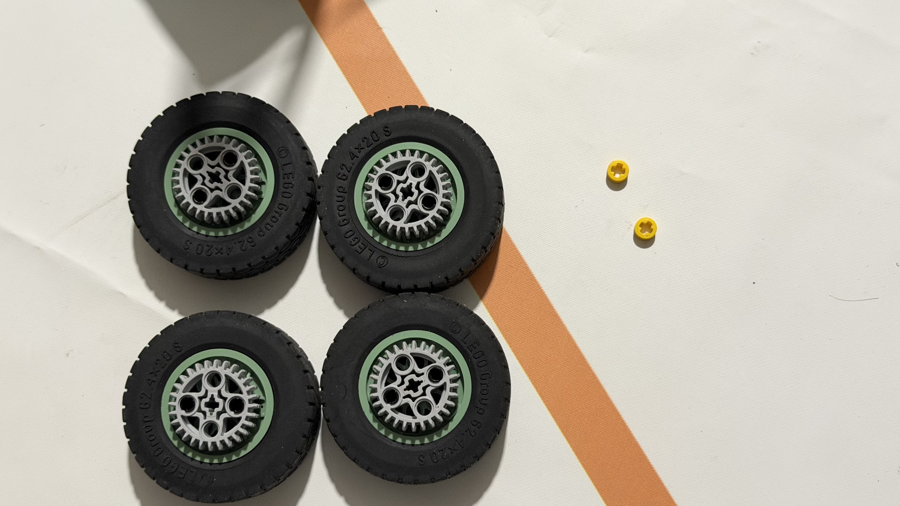
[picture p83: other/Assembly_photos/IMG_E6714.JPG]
Wheels ready to mount


The four tires along with their brass spacers, ready to be installed on the axles.

---

## Step 21 of 24 — First wheels installed

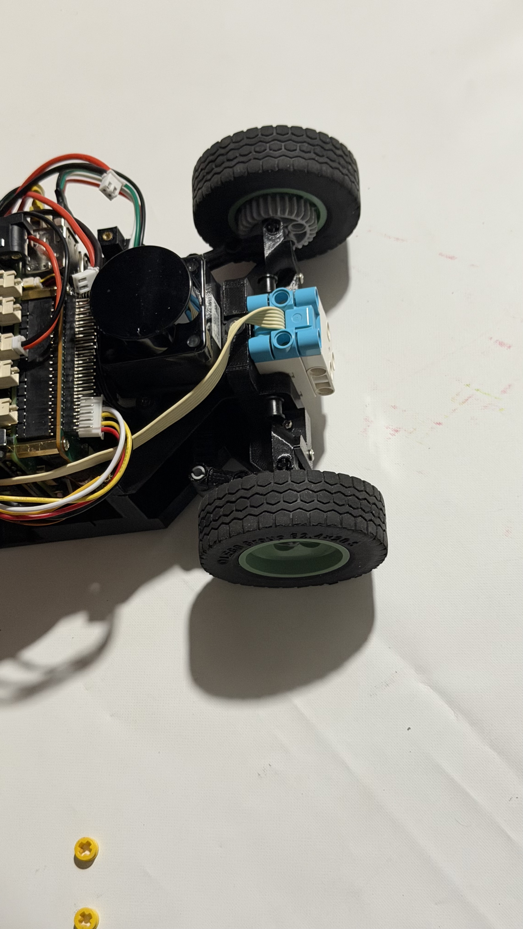
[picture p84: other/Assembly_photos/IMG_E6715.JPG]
First wheels installed


The first two rear wheels already installed on the chassis.

---

## Step 22 of 24 — Installing the front wheel

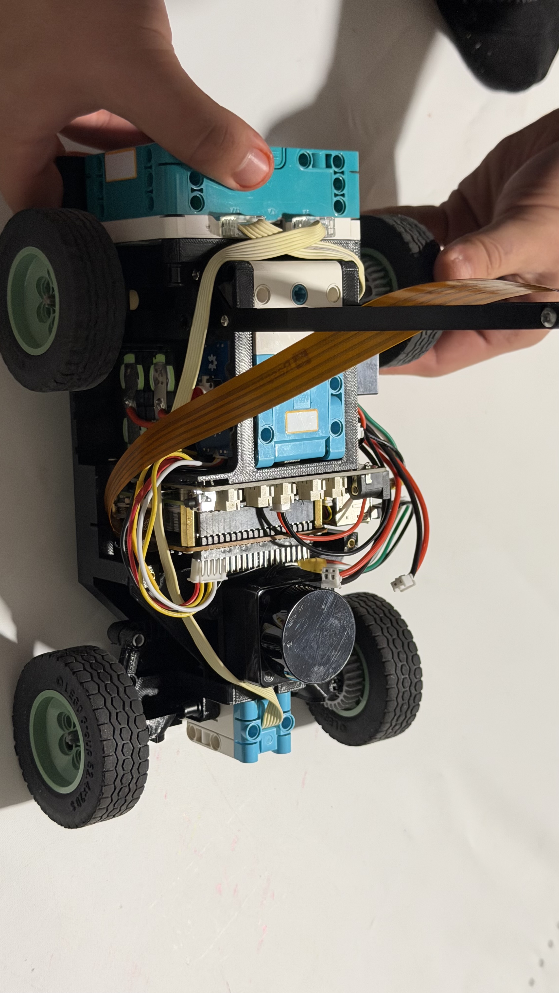
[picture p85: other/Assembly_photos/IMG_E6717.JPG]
Installing the front wheel


Mounting one of the front wheels onto the steering axle.

---

## Step 23 of 24 — All four wheels installed

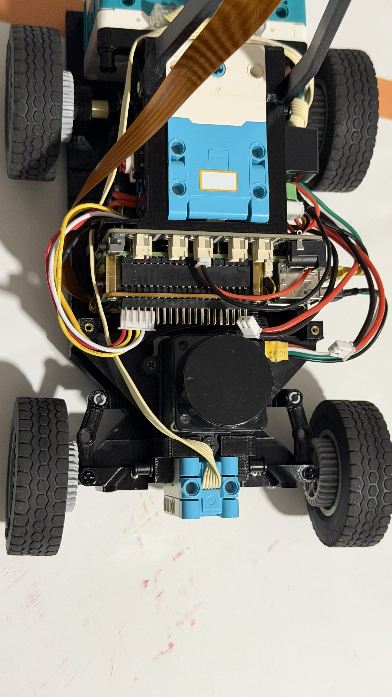
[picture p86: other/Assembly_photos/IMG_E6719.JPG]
All four wheels installed


Chassis with all four wheels now mounted: the robot can roll for the first time.

---

## Step 24 of 24 — Robot finished

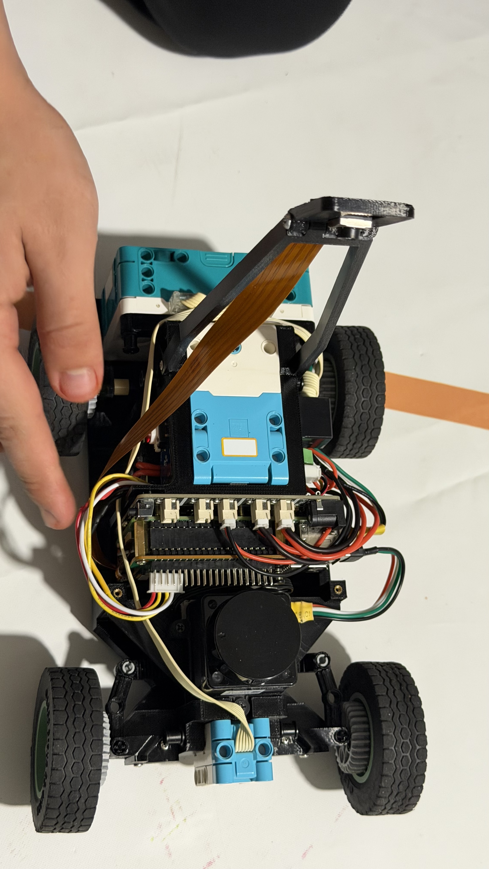
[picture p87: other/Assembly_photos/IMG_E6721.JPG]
Robot finished


Final wiring check with the robot fully assembled and resting on its four wheels.

---

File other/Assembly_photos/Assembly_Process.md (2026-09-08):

# Proceso de ensamblaje del robot

**WRO Future Engineers · Queretaro CSS**

50 fotografías seleccionadas, en orden cronológico de armado (según la fecha/hora EXIF de captura). Las fotos casi idénticas o sin relevancia adicional fueron omitidas.

---

## Paso 01 de 50 — Celda de batería individual

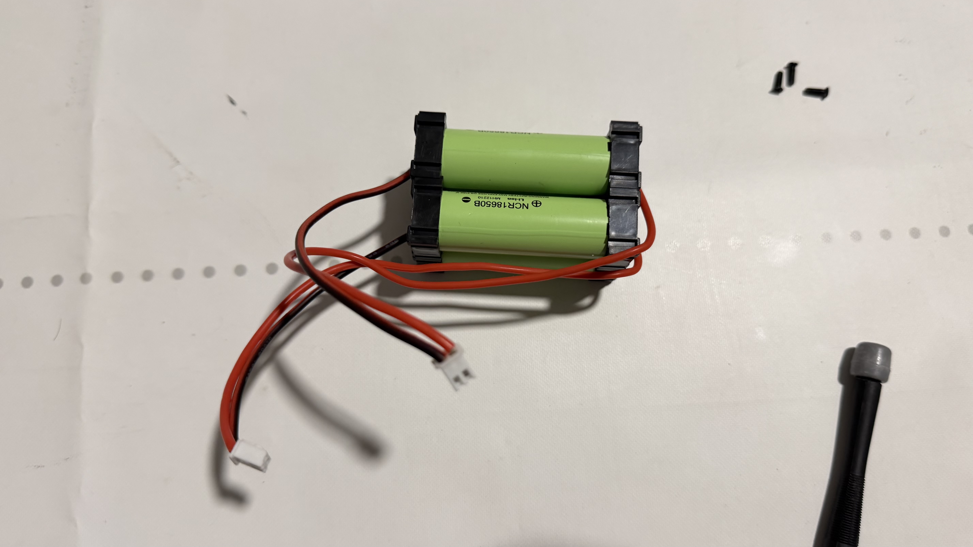
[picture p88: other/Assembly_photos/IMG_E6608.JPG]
Celda de batería individual


Una celda 18650 con sus cables positivo (rojo) y negativo (negro) ya soldados, pieza suelta antes de integrarse al paquete de baterías.

*Archivo original: `IMG_E6608.JPG`*

---

## Paso 02 de 50 — Motor de tracción con su driver

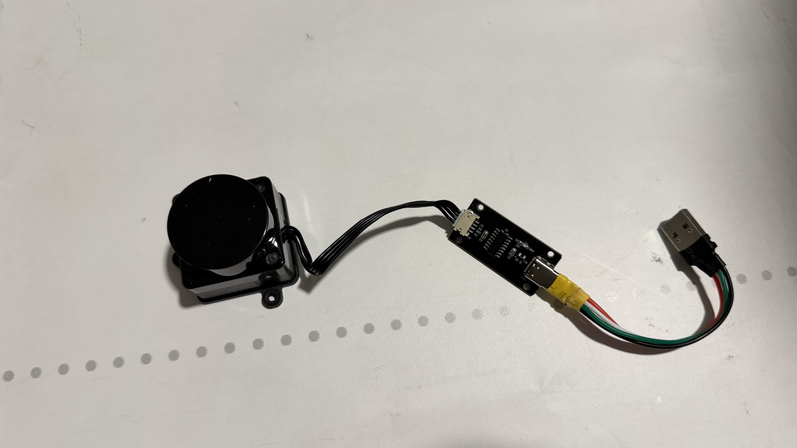
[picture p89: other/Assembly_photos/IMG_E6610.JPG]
Motor de tracción con su driver


Motor DC de tracción conectado a su controlador/ESC mediante el conector de 3 pines, listo para integrarse al chasis.

*Archivo original: `IMG_E6610.JPG`*

---

## Paso 03 de 50 — Cableado interno del chasis

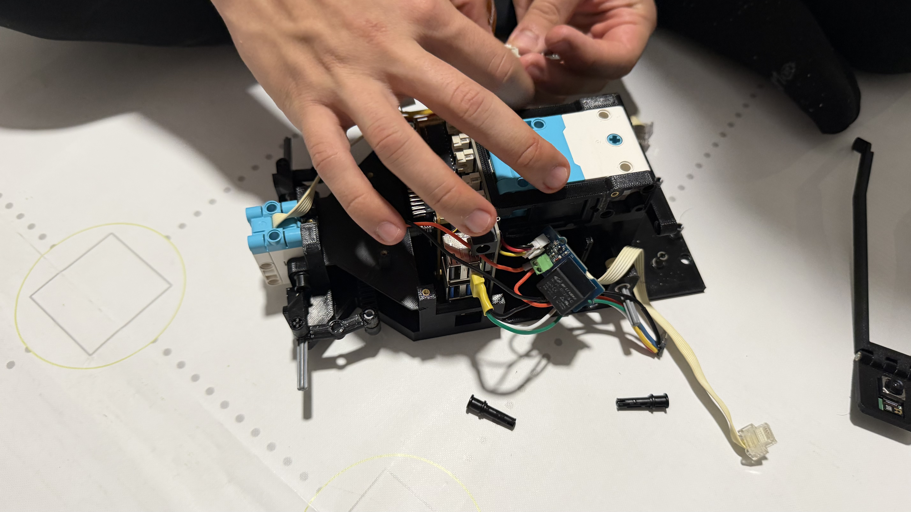
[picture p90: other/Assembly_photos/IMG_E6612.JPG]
Cableado interno del chasis


Ajustando manualmente el cableado y los conectores dentro de la estructura del chasis durante el armado inicial.

*Archivo original: `IMG_E6612.JPG`*

---

## Paso 04 de 50 — Raspberry Pi y HAT de IA

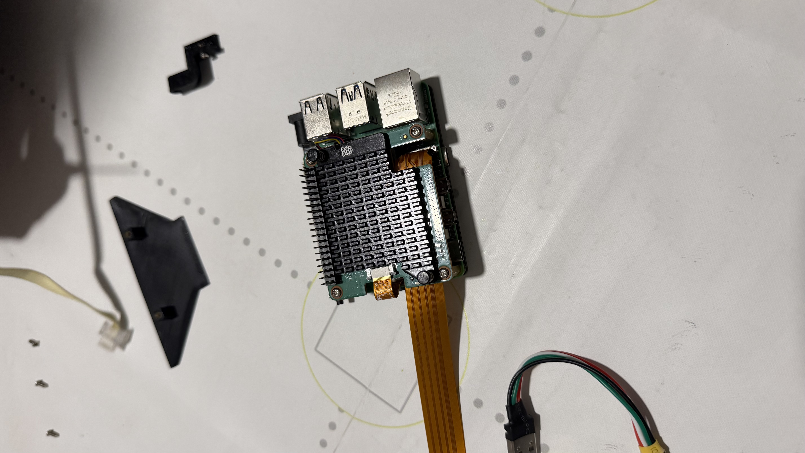
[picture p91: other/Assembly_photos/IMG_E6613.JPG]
Raspberry Pi y HAT de IA


Raspberry Pi con el HAT de inteligencia artificial (Hailo) apilado y el cable flex de la cámara ya conectado, antes de montarse en el chasis.

*Archivo original: `IMG_E6613.JPG`*

---

## Paso 05 de 50 — Todas las piezas listas

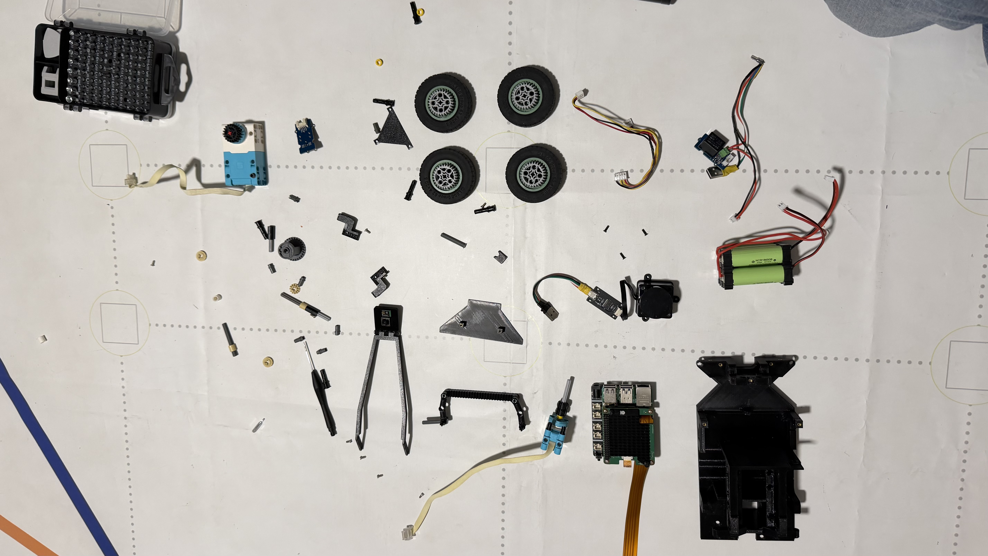
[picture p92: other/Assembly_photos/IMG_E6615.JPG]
Todas las piezas listas


Vista general de todas las piezas del robot -- ruedas, engranes, soportes impresos en 3D, batería, motores y placas -- organizadas antes de iniciar el armado.

*Archivo original: `IMG_E6615.JPG`*

---

## Paso 06 de 50 — Chasis impreso en 3D

Chasis impreso en 3D

Base y soporte de dirección del chasis, recién impresos en 3D, todavía sin electrónica ni tren motriz.

*Archivo original: `IMG_E6620.JPG`*

---

## Paso 07 de 50 — Piezas del sistema de dirección

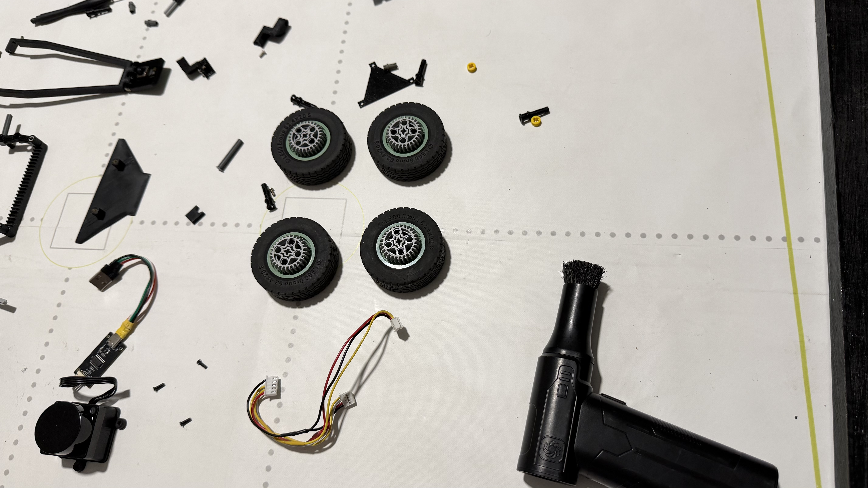
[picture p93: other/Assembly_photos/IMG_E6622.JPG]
Piezas del sistema de dirección


Ruedas, buje central y cableado del servo de dirección organizados antes de instalarse en el chasis.

*Archivo original: `IMG_E6622.JPG`*

---

## Paso 08 de 50 — Inicio del armado del chasis

Inicio del armado del chasis

Vista general del área de trabajo mientras se comienza a ensamblar la estructura del chasis.

*Archivo original: `IMG_E6623.JPG`*

---

## Paso 09 de 50 — Atornillando componentes internos

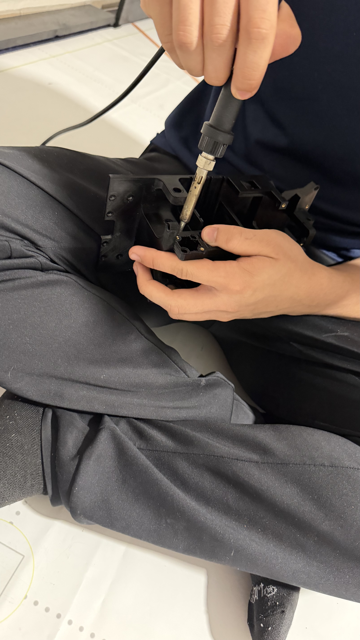
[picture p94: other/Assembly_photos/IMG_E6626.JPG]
Atornillando componentes internos


Primer plano fijando piezas dentro del chasis con un desarmador de precisión.

*Archivo original: `IMG_E6626.JPG`*

---

## Paso 10 de 50 — Ajuste final de la caja de engranes

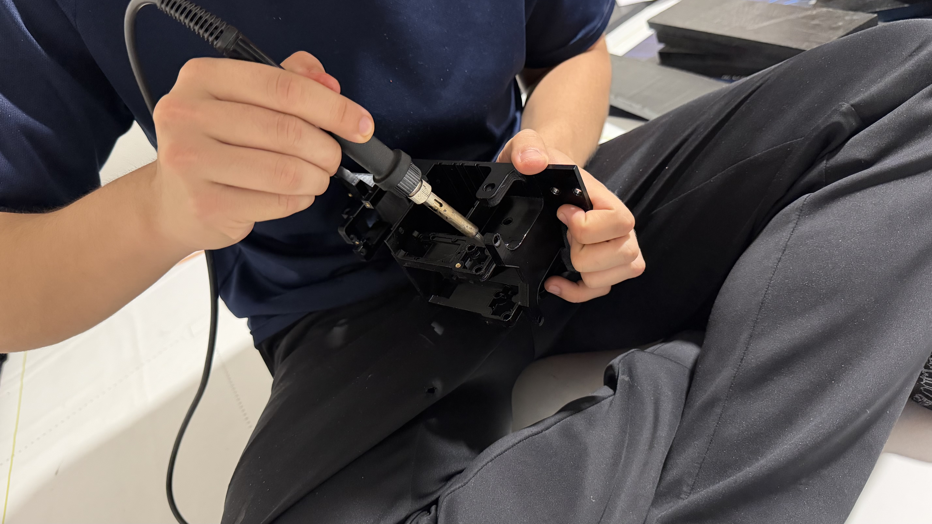
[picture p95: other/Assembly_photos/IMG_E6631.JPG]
Ajuste final de la caja de engranes


Apretando un tornillo final en la caja de engranajes recién ensamblada.

*Archivo original: `IMG_E6631.JPG`*

---

## Paso 11 de 50 — Caja de engranes vacía

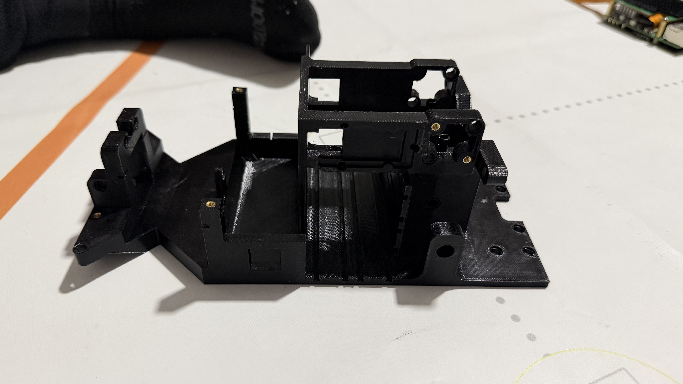
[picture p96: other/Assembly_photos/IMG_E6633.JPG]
Caja de engranes vacía


Caja de transmisión impresa en 3D vista desde arriba, todavía vacía, lista para recibir el motor y los engranes.

*Archivo original: `IMG_E6633.JPG`*

---

## Paso 12 de 50 — Ejes y engrane de tracción

Ejes y engrane de tracción

Flechas metálicas y el engrane/polea de tracción, piezas sueltas antes de montarse dentro de la caja de engranes.

*Archivo original: `IMG_E6634.JPG`*

---

## Paso 13 de 50 — Primer engrane instalado

Primer engrane instalado

Caja de engranajes con el primer engrane y su eje ya instalados dentro del chasis.

*Archivo original: `IMG_E6636.JPG`*

---

## Paso 14 de 50 — Fijando la tapa de la caja de engranes

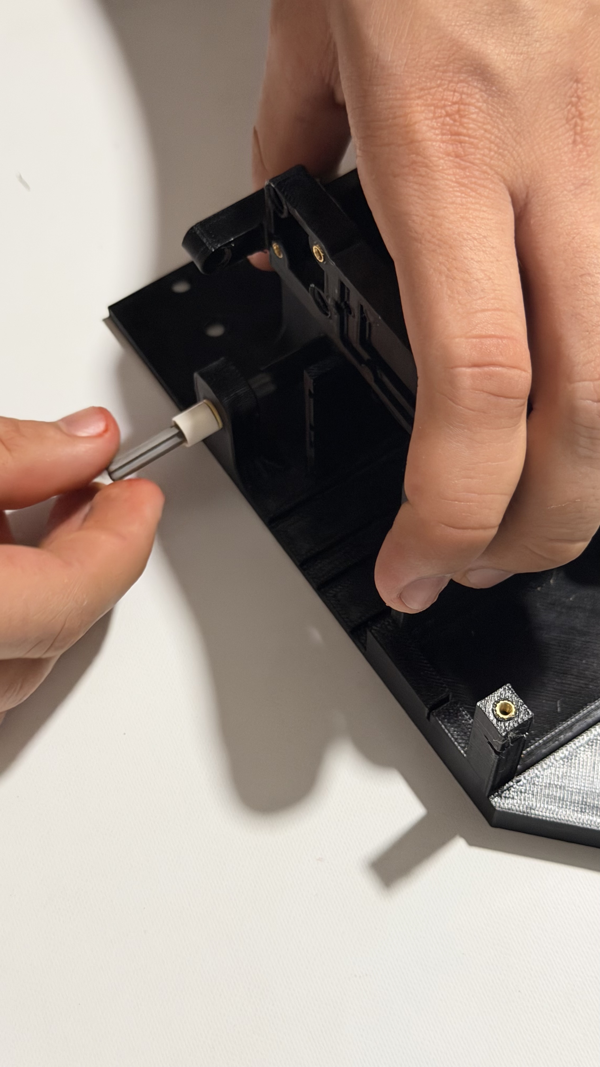
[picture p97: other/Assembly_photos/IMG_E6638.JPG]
Fijando la tapa de la caja de engranes


Atornillando la pieza lateral que cierra la caja de engranes con un desarmador pequeño.

*Archivo original: `IMG_E6638.JPG`*

---

## Paso 15 de 50 — Eje central de transmisión

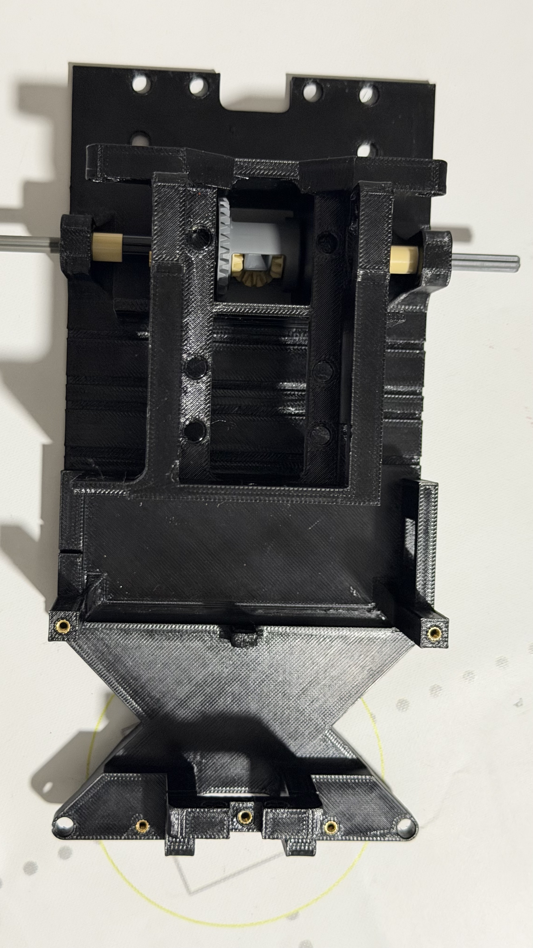
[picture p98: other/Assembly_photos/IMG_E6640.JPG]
Eje central de transmisión


Vista superior del chasis con el eje central de la transmisión ya instalado y pasante.

*Archivo original: `IMG_E6640.JPG`*

---

## Paso 16 de 50 — Instalando el servo de dirección

Instalando el servo de dirección

El servomotor de dirección (azul) siendo colocado en la parte frontal del chasis.

*Archivo original: `IMG_E6642.JPG`*

---

## Paso 17 de 50 — Servo de dirección en su soporte

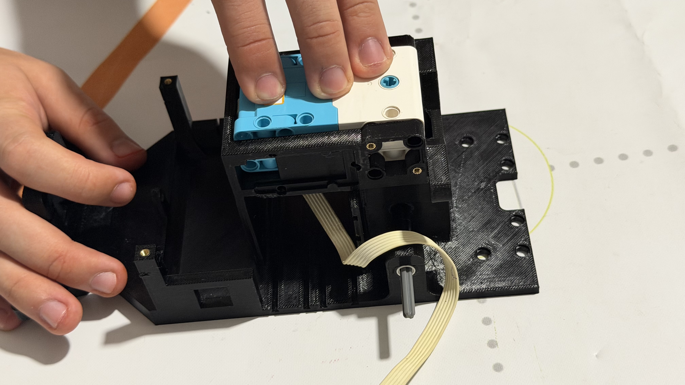
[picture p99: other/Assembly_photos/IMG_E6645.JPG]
Servo de dirección en su soporte


Ajustando el servo de dirección dentro de su soporte impreso en el chasis.

*Archivo original: `IMG_E6645.JPG`*

---

## Paso 18 de 50 — Placa de cómputo lista

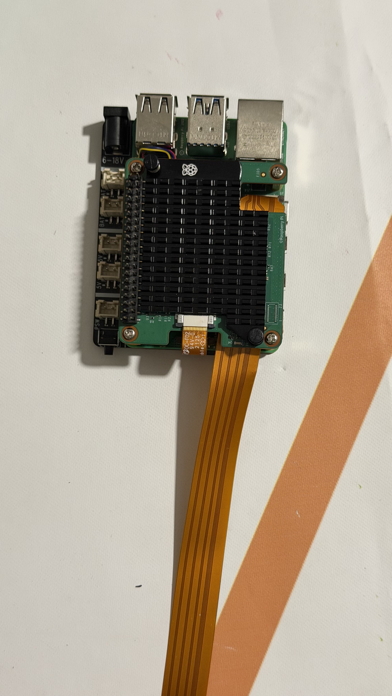
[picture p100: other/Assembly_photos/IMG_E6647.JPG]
Placa de cómputo lista


Raspberry Pi con el HAT de Hailo y el cable flex de la cámara ya integrados, lista para montarse sobre el chasis.

*Archivo original: `IMG_E6647.JPG`*

---

## Paso 19 de 50 — Dirección montada, chasis avanza

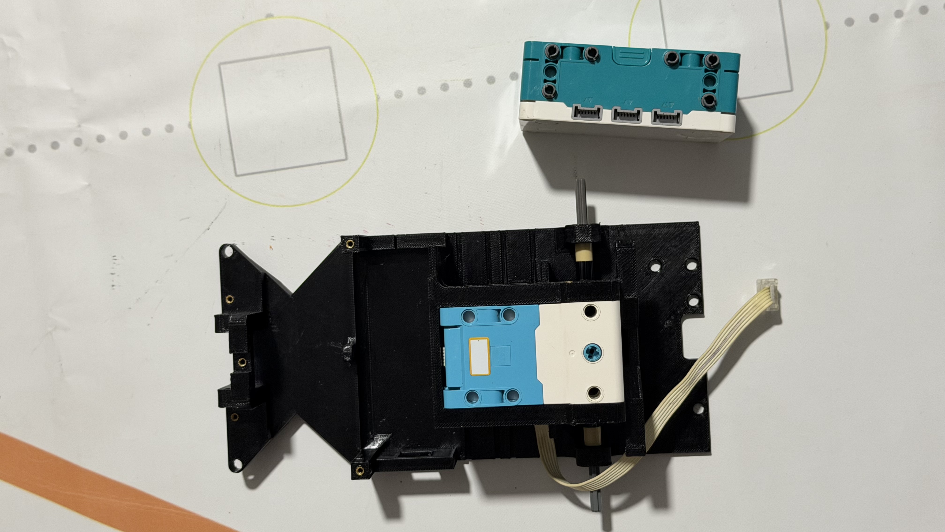
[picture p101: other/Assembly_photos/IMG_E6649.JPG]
Dirección montada, chasis avanza


Chasis con el servo de dirección ya fijo y el cable flex de la cámara pasado a través de la estructura.

*Archivo original: `IMG_E6649.JPG`*

---

## Paso 20 de 50 — Vista lateral con dirección instalada

Vista lateral con dirección instalada

Costado del chasis mostrando el servo de dirección y su cableado ya integrados.

*Archivo original: `IMG_E6652.JPG`*

---

## Paso 21 de 50 — Cerebro del robot integrado

Cerebro del robot integrado

La Raspberry Pi con el HAT de IA apilada sobre el chasis, con los cables flex ya conectados: el sistema de cómputo integrado a la estructura.

*Archivo original: `IMG_E6655.JPG`*

---

## Paso 22 de 50 — Fijando la placa de cómputo

Fijando la placa de cómputo

Ajustando y centrando la placa Raspberry Pi/HAT sobre el chasis para atornillarla.

*Archivo original: `IMG_E6658.JPG`*

---

## Paso 23 de 50 — Conectando el cable de la cámara

Conectando el cable de la cámara

Conectando el cable flex de la cámara directamente al conector CSI de la Raspberry Pi.

*Archivo original: `IMG_E6660.JPG`*

---

## Paso 24 de 50 — Placa de cómputo centrada

Placa de cómputo centrada

Vista superior del chasis con la placa de cómputo ya centrada y atornillada en su posición final.

*Archivo original: `IMG_E6663.JPG`*

---

## Paso 25 de 50 — Módulos Grove listos

Módulos Grove listos

Módulo Grove de botón con LED y módulo de relevador, con su cableado, listos para instalarse en el chasis.

*Archivo original: `IMG_E6664.JPG`*

---

## Paso 26 de 50 — Tren motriz por debajo

Tren motriz por debajo

Vista inferior del chasis mostrando el motor de tracción, los engranes y el cableado ya integrados.

*Archivo original: `IMG_E6666.JPG`*

---

## Paso 27 de 50 — Conexionado de motores

Conexionado de motores

Conectando los cables del motor y del servo a los conectores del driver dentro del chasis.

*Archivo original: `IMG_E6669.JPG`*

---

## Paso 28 de 50 — Batería instalada

Batería instalada

Chasis de pie con el paquete de baterías 18650 ya montado en la parte trasera.

*Archivo original: `IMG_E6675.JPG`*

---

## Paso 29 de 50 — Cableado principal acomodado

Cableado principal acomodado

Vista lateral del chasis con la batería y el cableado principal ya acomodados dentro de la estructura.

*Archivo original: `IMG_E6677.JPG`*

---

## Paso 30 de 50 — Vista trasera del chasis

Vista trasera del chasis

Parte posterior del chasis mostrando la batería y las conexiones traseras ya ordenadas.

*Archivo original: `IMG_E6680.JPG`*

---

## Paso 31 de 50 — Piezas del soporte trasero

Piezas del soporte trasero

Brazo de dirección trasero y tornillería sueltos, antes de montarse en el eje posterior.

*Archivo original: `IMG_E6681.JPG`*

---

## Paso 32 de 50 — Instalando el brazo trasero

Instalando el brazo trasero

Montando el brazo/soporte trasero sobre el eje de dirección del chasis.

*Archivo original: `IMG_E6683.JPG`*

---

## Paso 33 de 50 — Eje trasero ensamblado

Eje trasero ensamblado

Eje trasero con el brazo de dirección y los conectores azules ya montados, visto desde atrás.

*Archivo original: `IMG_E6684.JPG`*

---

## Paso 34 de 50 — Soportes en L y tornillería

Soportes en L y tornillería

Piezas de sujeción en forma de L, impresas en 3D, junto con sus tornillos, antes de integrarse al chasis.

*Archivo original: `IMG_E6686.JPG`*

---

## Paso 35 de 50 — Eje delantero listo para ruedas

Eje delantero listo para ruedas

Eje delantero con el brazo de dirección ya instalado, listo para recibir las ruedas.

*Archivo original: `IMG_E6688.JPG`*

---

## Paso 36 de 50 — Atornillando el soporte de dirección

Atornillando el soporte de dirección

Fijando el soporte de dirección con un desarmador pequeño.

*Archivo original: `IMG_E6690.JPG`*

---

## Paso 37 de 50 — Soporte de cámara y motor

Soporte de cámara y motor

Soporte triangular de la cámara junto con un motor y su cableado, piezas sueltas antes de montarse.

*Archivo original: `IMG_E6696.JPG`*

---

## Paso 38 de 50 — Instalando el módulo lidar

Instalando el módulo lidar

Montando el módulo cilíndrico del lidar en la parte superior del chasis.

*Archivo original: `IMG_E6698.JPG`*

---

## Paso 39 de 50 — Lidar integrado

Lidar integrado

Chasis con el módulo del lidar ya integrado en la parte superior de la estructura.

*Archivo original: `IMG_E6700.JPG`*

---

## Paso 40 de 50 — Ajustando el módulo superior

Ajustando el módulo superior

Manos ajustando y fijando el módulo recién instalado en la parte alta del chasis.

*Archivo original: `IMG_E6702.JPG`*

---

## Paso 41 de 50 — Electrónica superior integrada

Electrónica superior integrada

Vista lateral del chasis con el lidar, la cámara y la placa de cómputo ya integrados juntos.

*Archivo original: `IMG_E6704.JPG`*

---

## Paso 42 de 50 — Chasis casi completo

Chasis casi completo

El chasis de pie, mostrando toda la electrónica principal ya integrada verticalmente.

*Archivo original: `IMG_E6706.JPG`*

---

## Paso 43 de 50 — Ensamble completo sin ruedas

Ensamble completo sin ruedas

Vista superior del chasis totalmente ensamblado, todavía sin las ruedas instaladas.

*Archivo original: `IMG_E6708.JPG`*

---

## Paso 44 de 50 — Último ajuste de cableado

Último ajuste de cableado

Ajustando un cable final con pinzas antes de proceder a instalar las ruedas.

*Archivo original: `IMG_E6711.JPG`*

---

## Paso 45 de 50 — Cableado completo a la vista

Cableado completo a la vista

Chasis recostado de lado, mostrando el cableado completo recorriendo toda la estructura.

*Archivo original: `IMG_E6712.JPG`*

---

## Paso 46 de 50 — Ruedas listas para montar

Ruedas listas para montar

Las cuatro llantas junto con sus separadores dorados, listas para instalarse en los ejes.

*Archivo original: `IMG_E6714.JPG`*

---

## Paso 47 de 50 — Primeras ruedas instaladas

Primeras ruedas instaladas

Las dos primeras ruedas traseras ya instaladas en el chasis.

*Archivo original: `IMG_E6715.JPG`*

---

## Paso 48 de 50 — Instalando rueda delantera

Instalando rueda delantera

Montando una de las ruedas delanteras en el eje de dirección.

*Archivo original: `IMG_E6717.JPG`*

---

## Paso 49 de 50 — Las cuatro ruedas instaladas

Las cuatro ruedas instaladas

Chasis con las cuatro ruedas ya montadas: el robot puede rodar por primera vez.

*Archivo original: `IMG_E6719.JPG`*

---

## Paso 50 de 50 — Robot terminado

Robot terminado

Revisión final del cableado con el robot completamente armado y apoyado sobre sus cuatro ruedas.

*Archivo original: `IMG_E6721.JPG`*

---

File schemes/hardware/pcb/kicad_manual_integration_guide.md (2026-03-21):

# KiCad Manual Integration Guide

## Objetivo
Reemplazar los bloques placeholder por símbolos reales de KiCad y conectarlos a las etiquetas jerárquicas ya existentes.

## Símbolos a usar
- **MCU**: `MCU_ST_STM32F1:STM32F103R_C-D-E_Tx`
- **IMU**: `Sensor_Motion:ICM-20948`
- **SWD/UART/Batería/Motor/Encoder**: `Connector_Generic:Conn_01x0X`
- **Motor driver (si existe en librería local o externa)**: `AM2861`

## Flujo recomendado en KiCad

### 1. Abrir el proyecto
- Abre `hardware/pcb/future_engineers_robotics_expansion.kicad_pro`
- Entra al editor esquemático

### 2. Integrar el MCU real
- Abre la hoja `mcu.kicad_sch`
- Selecciona el bloque `U1` placeholder y elimínalo
- Presiona `A` para agregar símbolo
- Busca `STM32F103R_C-D-E_Tx`
- Selecciona `MCU_ST_STM32F1:STM32F103R_C-D-E_Tx`
- Colócalo en el centro de la hoja
- Edita propiedades:
  - **Reference**: `U1`
  - **Value**: `STM32F103RCT6`
  - **Footprint**: `Package_QFP:LQFP-64_10x10mm_P0.5mm`

### 3. Cableado mínimo del MCU
Conecta estos pines del símbolo a las etiquetas jerárquicas:

- `NRST` -> `NRST`
- `BOOT0` -> `BOOT0`
- `PA13 / SYS_JTMS-SWDIO` -> `SWDIO`
- `PA14 / SYS_JTCK-SWCLK` -> `SWCLK`
- `PA9 / USART1_TX` -> `UART_TX`
- `PA10 / USART1_RX` -> `UART_RX`
- `PB6 / I2C1_SCL` -> `IMU_SCL_SCLK`
- `PB7 / I2C1_SDA` -> `IMU_SDA_SDI`
- `PB8 / TIM4_CH3` -> `M1`
- `PB0` -> `M1A`
- `PB1` -> `M1B`
- `VDD`, `VDDA`, `VBAT` -> `+3V3`
- `VSS`, `VSSA` -> `GND` / `AGND`

### 4. Integrar la IMU real
- Abre `imu.kicad_sch`
- Elimina el placeholder `U5`
- Presiona `A`
- Busca `ICM-20948`
- Selecciona `Sensor_Motion:ICM-20948`
- Configura:
  - **Reference**: `U5`
  - **Value**: `ICM-20948`
  - **Footprint**: `Sensor_Motion:InvenSense_QFN-24_3x3mm_P0.4mm`

### 5. Cableado mínimo de la IMU
- `SDO/AD0` -> `IMU_AD0_SDO`
- `SDA/SDI` -> `IMU_SDA_SDI`
- `SCL/SCLK` -> `IMU_SCL_SCLK`
- `~CS` -> `IMU_nCS`
- `INT1` -> `IMU_INT`
- `VDDIO` -> `+3V3`
- `VDD` -> `+3V3`
- `GND` -> `GND`

### 6. Integrar conectores reales
#### Debug
- Usa `Conn_01x04` o `Conn_02x03`
- Mapea: `3V3`, `SWDIO`, `SWCLK`, `GND`, opcional `NRST`

#### UART
- Usa `Conn_01x03`
- Mapea: `GND`, `UART_TX`, `UART_RX`

#### Batería
- Usa `Conn_01x02`
- Mapea: `BAT+`, `GND`

#### Motor / Encoder
- Usa `Conn_01x06`
- Mapea: `VM`, `M1+`, `M1-`, `H1A`, `H1B`, `GND`

### 7. Power sheet
En `power.kicad_sch` agrega:
- protección por inversión (`P-MOSFET` o Schottky)
- `SMBJ14A`
- capacitor bulk 470uF-1000uF
- buck 12V->5V
- LDO 5V->3V3

### 8. Validación
- Ejecuta ERC después de cada hoja importante
- Primero valida `mcu`
- Luego `imu`
- Luego `debug/connectors/power`

## Consejos prácticos
- No intentes limpiar todo el ERC en una sola pasada
- Primero reemplaza símbolo, luego conecta señales principales
- Si un símbolo no está en librería estándar, deja temporalmente el bloque pero actualiza `Value`, `Footprint` y `Datasheet`
- Guarda después de cada reemplazo importante

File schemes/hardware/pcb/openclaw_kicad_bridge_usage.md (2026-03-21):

# OpenClaw KiCad Host Bridge Usage

## Purpose
Puente local mínimo para que el host Windows pueda abrir y enfocar KiCad desde terminal, coordinado por Cascade/OpenClaw.

## Script
- `hardware/pcb/kicad_host_bridge.ps1`

## Supported actions
- `open_project`
- `focus_kicad`
- `status`
- `send_keys`
- `window_info`
- `click_relative`
- `capture_window`
- `click_and_type`
- `click_and_paste`

## Examples

### Open KiCad project
```powershell
powershell -ExecutionPolicy Bypass -File "c:\Users\jesus\WRO_Future_Engineers_Queretaro_CSS\hardware\pcb\kicad_host_bridge.ps1" -Action open_project
```

### Focus KiCad window
```powershell
powershell -ExecutionPolicy Bypass -File "c:\Users\jesus\WRO_Future_Engineers_Queretaro_CSS\hardware\pcb\kicad_host_bridge.ps1" -Action focus_kicad
```

### Check status
```powershell
powershell -ExecutionPolicy Bypass -File "c:\Users\jesus\WRO_Future_Engineers_Queretaro_CSS\hardware\pcb\kicad_host_bridge.ps1" -Action status
```

### Send keys to KiCad
```powershell
powershell -ExecutionPolicy Bypass -File "c:\Users\jesus\WRO_Future_Engineers_Queretaro_CSS\hardware\pcb\kicad_host_bridge.ps1" -Action send_keys -Keys "^s"
```

### Open the symbol dialog shortcut example
```powershell
powershell -ExecutionPolicy Bypass -File "c:\Users\jesus\WRO_Future_Engineers_Queretaro_CSS\hardware\pcb\kicad_host_bridge.ps1" -Action send_keys -Keys "a"
```

### Read KiCad window bounds
```powershell
powershell -ExecutionPolicy Bypass -File "c:\Users\jesus\WRO_Future_Engineers_Queretaro_CSS\hardware\pcb\kicad_host_bridge.ps1" -Action window_info
```

### Click relative to KiCad window
```powershell
powershell -ExecutionPolicy Bypass -File "c:\Users\jesus\WRO_Future_Engineers_Queretaro_CSS\hardware\pcb\kicad_host_bridge.ps1" -Action click_relative -X 200 -Y 150
```

### Capture the targeted KiCad window
```powershell
powershell -ExecutionPolicy Bypass -File "c:\Users\jesus\WRO_Future_Engineers_Queretaro_CSS\hardware\pcb\kicad_host_bridge.ps1" -Action capture_window -Target eeschema -OutputPath "c:\Users\jesus\WRO_Future_Engineers_Queretaro_CSS\hardware\pcb\kicad_window_capture.png"
```

### Click and type in one execution
```powershell
powershell -ExecutionPolicy Bypass -File "c:\Users\jesus\WRO_Future_Engineers_Queretaro_CSS\hardware\pcb\kicad_host_bridge.ps1" -Action click_and_type -Target eeschema -X 155 -Y 111 -Keys "STM32F103R_C-D-E_Tx" -DelayMs 1000 -OutputPath "c:\Users\jesus\WRO_Future_Engineers_Queretaro_CSS\hardware\pcb\kicad_window_capture_after_click_and_type.png"
```

### Click and paste in one execution
```powershell
powershell -ExecutionPolicy Bypass -File "c:\Users\jesus\WRO_Future_Engineers_Queretaro_CSS\hardware\pcb\kicad_host_bridge.ps1" -Action click_and_paste -Target eeschema -X 155 -Y 111 -Keys "STM32F103R_C-D-E_Tx" -DelayMs 1000 -OutputPath "c:\Users\jesus\WRO_Future_Engineers_Queretaro_CSS\hardware\pcb\kicad_window_capture_after_click_and_paste.png"
```

## Next step
Después de validar apertura/enfoque, ampliar el bridge con acciones como:
- abrir hoja `mcu`
- enviar teclas controladas
- automatizar inserción de símbolos
- guardar proyecto

## Notes
Este bridge ya puede abrir, enfocar, enviar teclas, hacer clics relativos, capturar, ejecutar click+type y click+paste en un solo paso. Aun así, la automatización sigue siendo sensible al layout visual y conviene avanzar paso a paso.

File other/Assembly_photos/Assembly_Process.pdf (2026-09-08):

# Proceso de ensamblaje del robot

WRO FUTURE ENGINEERS · QUERETARO CSS

50 fotografias seleccionadas, en orden cronologico de armado (a partir de la fecha/hora EXIF de captura)

PASO 01 de 50

## Celda de batería individual

Una celda 18650 con sus cables positivo (rojo) y negativo (negro) ya soldados, pieza suelta antes de integrarse al paquete de baterías.

IMG_E6608.JPG

PASO 02 de 50

## Motor de tracción con su driver

Motor DC de tracción conectado a su controlador/ESC mediante el conector de 3 pines, listo para integrarse al chasis.

IMG_E6610.JPG

PASO 03 de 50

## Cableado interno del chasis

Ajustando manualmente el cableado y los conectores dentro de la estructura del chasis durante el armado inicial.

IMG_E6612.JPG

PASO 04 de 50

## Raspberry Pi y HAT de IA

Raspberry Pi con el HAT de inteligencia artificial (Hailo) apilado y el cable flex de la cámara ya conectado, antes de montarse en el chasis.

IMG_E6613.JPG

PASO 05 de 50

## Todas las piezas listas

Vista general de todas las piezas del robot -- ruedas, engranes, soportes impresos en 3D, batería, motores y placas -- organizadas antes de iniciar el armado.

IMG_E6615.JPG

PASO 06 de 50

## Chasis impreso en 3D

Base y soporte de dirección del chasis, recién impresos en 3D, todavía sin electrónica ni tren motriz.

IMG_E6620.JPG

PASO 07 de 50

## Piezas del sistema de dirección

Ruedas, buje central y cableado del servo de dirección organizados antes de instalarse en el chasis.

IMG_E6622.JPG

PASO 08 de 50

## Inicio del armado del chasis

Vista general del área de trabajo mientras se comienza a ensamblar la estructura del chasis.

IMG_E6623.JPG

PASO 09 de 50

## Atornillando componentes internos


Primer plano fijando piezas dentro del chasis con un desarmador de precisión.

IMG_E6626.JPG

PASO 10 de 50

## Ajuste final de la caja de engranes

Apretando un tornillo final en la caja de engranajes recién ensamblada.

IMG_E6631.JPG

PASO 11 de 50

## Caja de engranes vacía

Caja de transmisión impresa en 3D vista desde arriba, todavía vacía, lista para recibir el motor y los engranes.

IMG_E6633.JPG

PASO 12 de 50

## Ejes y engrane de tracción

Flechas metálicas y el engrane/polea de tracción, piezas sueltas antes de montarse dentro de la caja de engranes.

IMG_E6634.JPG

PASO 13 de 50

## Primer engrane instalado


Caja de engranajes con el primer engrane y su eje ya instalados dentro del chasis.

IMG_E6636.JPG

PASO 14 de 50

## Fijando la tapa de la caja de engranes


Atornillando la pieza lateral que cierra la caja de engranes con un desarmador pequeño.

IMG_E6638.JPG

PASO 15 de 50

## Eje central de transmisión


Vista superior del chasis con el eje central de la transmisión ya instalado y pasante.

IMG_E6640.JPG

PASO 16 de 50

## Instalando el servo de dirección


El servomotor de dirección (azul) siendo colocado en la parte frontal del chasis.

IMG_E6642.JPG

PASO 17 de 50

## Servo de dirección en su soporte

Ajustando el servo de dirección dentro de su soporte impreso en el chasis.

IMG_E6645.JPG

PASO 18 de 50

## Placa de cómputo lista


Raspberry Pi con el HAT de Hailo y el cable flex de la cámara ya integrados, lista para montarse sobre el chasis.

IMG_E6647.JPG

PASO 19 de 50

## Dirección montada, chasis avanza

Chasis con el servo de dirección ya fijo y el cable flex de la cámara pasado a través de la estructura.

IMG_E6649.JPG

PASO 20 de 50

## Vista lateral con dirección instalada

Costado del chasis mostrando el servo de dirección y su cableado ya integrados.

IMG_E6652.JPG

PASO 21 de 50

## Cerebro del robot integrado


La Raspberry Pi con el HAT de IA apilada sobre el chasis, con los cables flex ya conectados: el sistema de cómputo integrado a la estructura.

IMG_E6655.JPG

PASO 22 de 50

## Fijando la placa de cómputo

Ajustando y centrando la placa Raspberry Pi/HAT sobre el chasis para atornillarla.

IMG_E6658.JPG

PASO 23 de 50

## Conectando el cable de la cámara

Conectando el cable flex de la cámara directamente al conector CSI de la Raspberry Pi.

IMG_E6660.JPG

PASO 24 de 50

## Placa de cómputo centrada

Vista superior del chasis con la placa de cómputo ya centrada y atornillada en su posición final.

IMG_E6663.JPG

PASO 25 de 50

## Módulos Grove listos

Módulo Grove de botón con LED y módulo de relevador, con su cableado, listos para instalarse en el chasis.

IMG_E6664.JPG

PASO 26 de 50

## Tren motriz por debajo

Vista inferior del chasis mostrando el motor de tracción, los engranes y el cableado ya integrados.

IMG_E6666.JPG

PASO 27 de 50

## Conexionado de motores

Conectando los cables del motor y del servo a los conectores del driver dentro del chasis.

IMG_E6669.JPG

PASO 28 de 50

## Batería instalada


Chasis de pie con el paquete de baterías 18650 ya montado en la parte trasera.

IMG_E6675.JPG

PASO 29 de 50

## Cableado principal acomodado

Vista lateral del chasis con la batería y el cableado principal ya acomodados dentro de la estructura.

IMG_E6677.JPG

PASO 30 de 50

## Vista trasera del chasis


Parte posterior del chasis mostrando la batería y las conexiones traseras ya ordenadas.

IMG_E6680.JPG

PASO 31 de 50

## Piezas del soporte trasero


Brazo de dirección trasero y tornillería sueltos, antes de montarse en el eje posterior.

IMG_E6681.JPG

PASO 32 de 50

## Instalando el brazo trasero


Montando el brazo/soporte trasero sobre el eje de dirección del chasis.

IMG_E6683.JPG

PASO 33 de 50

## Eje trasero ensamblado


Eje trasero con el brazo de dirección y los conectores azules ya montados, visto desde atrás.

IMG_E6684.JPG

PASO 34 de 50

## Soportes en L y tornillería

Piezas de sujeción en forma de L, impresas en 3D, junto con sus tornillos, antes de integrarse al chasis.

IMG_E6686.JPG

PASO 35 de 50

## Eje delantero listo para ruedas

Eje delantero con el brazo de dirección ya instalado, listo para recibir las ruedas.

IMG_E6688.JPG

PASO 36 de 50

## Atornillando el soporte de dirección

Fijando el soporte de dirección con un desarmador pequeño.

IMG_E6690.JPG

PASO 37 de 50

## Soporte de cámara y motor


Soporte triangular de la cámara junto con un motor y su cableado, piezas sueltas antes de montarse.

IMG_E6696.JPG

PASO 38 de 50

## Instalando el módulo lidar

Montando el módulo cilíndrico del lidar en la parte superior del chasis.

IMG_E6698.JPG

PASO 39 de 50

## Lidar integrado


Chasis con el módulo del lidar ya integrado en la parte superior de la estructura.

IMG_E6700.JPG

PASO 40 de 50

## Ajustando el módulo superior


Manos ajustando y fijando el módulo recién instalado en la parte alta del chasis.

IMG_E6702.JPG

PASO 41 de 50

## Electrónica superior integrada


Vista lateral del chasis con el lidar, la cámara y la placa de cómputo ya integrados juntos.

IMG_E6704.JPG

PASO 42 de 50

## Chasis casi completo


El chasis de pie, mostrando toda la electrónica principal ya integrada verticalmente.

IMG_E6706.JPG

PASO 43 de 50

## Ensamble completo sin ruedas


Vista superior del chasis totalmente ensamblado, todavía sin las ruedas instaladas.

IMG_E6708.JPG

PASO 44 de 50

## Último ajuste de cableado

Ajustando un cable final con pinzas antes de proceder a instalar las ruedas.

IMG_E6711.JPG

PASO 45 de 50

## Cableado completo a la vista

Chasis recostado de lado, mostrando el cableado completo recorriendo toda la estructura.

IMG_E6712.JPG

PASO 46 de 50

## Ruedas listas para montar

Las cuatro llantas junto con sus separadores dorados, listas para instalarse en los ejes.

IMG_E6714.JPG

PASO 47 de 50

## Primeras ruedas instaladas


Las dos primeras ruedas traseras ya instaladas en el chasis.

IMG_E6715.JPG

PASO 48 de 50

## Instalando rueda delantera


Montando una de las ruedas delanteras en el eje de dirección.

IMG_E6717.JPG

PASO 49 de 50

## Las cuatro ruedas instaladas


Chasis con las cuatro ruedas ya montadas: el robot puede rodar por primera vez.

IMG_E6719.JPG

PASO 50 de 50

## Robot terminado


Revisión final del cableado con el robot completamente armado y apoyado sobre sus cuatro ruedas.

IMG_E6721.JPG

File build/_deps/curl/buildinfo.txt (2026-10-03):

# This is a generated file.  Do not edit.
buildinfo.configure.tool: cmake
buildinfo.configure.command: /usr/bin/cmake
buildinfo.configure.version: 3.31.6
buildinfo.configure.args:
buildinfo.configure.generator: Ninja
buildinfo.configure.make: /usr/bin/ninja
buildinfo.host.cpu: aarch64
buildinfo.host.os: Linux
buildinfo.target.cpu: aarch64
buildinfo.target.os: Linux
buildinfo.target.flags: UNIX GCC
buildinfo.compiler: GNU
buildinfo.compiler.version: 14.2.0
buildinfo.sysroot:

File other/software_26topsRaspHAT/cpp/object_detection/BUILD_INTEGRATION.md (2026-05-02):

# Adding New Source Files to the Object Detection Build

## Context

The project at `hailo_apps/cpp/object_detection/` uses **CMake** as its build system.
Running CMake produces a generated `Makefile` inside `build/aarch64/`. The header of
that file reads:

```
# CMAKE generated file: DO NOT EDIT!
# Generated by "Unix Makefiles" Generat7or, CMake Version 3.31
```

This means **you must never edit `build/aarch64/Makefile` by hand**. Any manual edit
is overwritten the next time CMake runs. The correct place to declare sources,
include paths, and link libraries is `CMakeLists.txt`.

---

## New Files Added

Three new translation units were placed in the source directory:

| File | Purpose | Extra dependency |
|---|---|---|
| `rasp_gpio.cpp` / `.h` | Raspberry Pi GPIO control via `libgpiod` | `gpiod` |
| `RPLidar_S2L.cpp` / `.h` | RPLidar S2L driver (serial communication + scan parsing) | RPLidar SDK (`libsl_lidar_sdk.a`) |
| `spike.cpp` / `.h` | LEGO Spike Prime serial interface | none (standard C headers only) |

Also present but header-only: `common_var.h` (shared type definitions used by the above).

---

## Why CMake Didn't Pick Them Up Automatically

`CMakeLists.txt` uses a glob to collect sources:

```cmake
file(GLOB SOURCES
    "${CMAKE_CURRENT_SOURCE_DIR}/*.cpp"
    "${CMAKE_CURRENT_SOURCE_DIR}/utils/*.cpp"
)
```

CMake evaluates globs **at configure time** (when you run `cmake`), not at build time
(when you run `make`). The build directory was configured before the new `.cpp` files
existed, so the generated `Makefile` had no knowledge of them. Simply dropping files
into the source folder is not enough — CMake must be re-run.

---

## Dependency Analysis

### `rasp_gpio.cpp`

The header includes:

```cpp
#include <gpiod.h>
```

This requires the `libgpiod` development package (present on the system:
`libgpiod-dev:arm64 2.2.1-2+deb13u1`) and linking against `-lgpiod`.

### `RPLidar_S2L.cpp`

The header includes:

```cpp
#include <sl_lidar.h>
#include <sl_lidar_driver.h>
```

These headers and the pre-built static library live inside the project:

```
object_detection/rplidar_sdk/
├── sdk/
│   ├── include/      ← headers (sl_lidar.h, sl_lidar_driver.h, …)
│   └── src/          ← internal SDK source headers
└── output/Linux/Release/
    └── libsl_lidar_sdk.a   ← pre-built static library
```

### `spike.cpp`

Uses only standard C headers (`stdio.h`, `stdlib.h`, `termios.h`, etc.).
No additional link libraries are required.

---

## Changes Made to `CMakeLists.txt`

Two sections were modified.

### 1. RPLidar SDK variables + include directories

**Before:**

```cmake
# ============================================================
# Include dirs
# ============================================================
target_include_directories(${PROJECT_NAME} PRIVATE
    ${OpenCV_INCLUDE_DIRS}
    ${CMAKE_CURRENT_SOURCE_DIR}
    ${CMAKE_CURRENT_SOURCE_DIR}/utils
    "${CMAKE_CURRENT_SOURCE_DIR}/../common"
)
```

**After:**

```cmake
# ============================================================
# RPLidar SDK
# ============================================================
set(RPLIDAR_SDK_DIR "${CMAKE_CURRENT_SOURCE_DIR}/rplidar_sdk")
set(RPLIDAR_LIB "${RPLIDAR_SDK_DIR}/output/Linux/Release/libsl_lidar_sdk.a")

# ============================================================
# Include dirs
# ============================================================
target_include_directories(${PROJECT_NAME} PRIVATE
    ${OpenCV_INCLUDE_DIRS}
    ${CMAKE_CURRENT_SOURCE_DIR}
    ${CMAKE_CURRENT_SOURCE_DIR}/utils
    "${CMAKE_CURRENT_SOURCE_DIR}/../common"
    "${RPLIDAR_SDK_DIR}/sdk/include"
    "${RPLIDAR_SDK_DIR}/sdk/src"
)
```

Two new include paths are added so the compiler can find `<sl_lidar.h>` and the
internal SDK headers used by the driver.

### 2. Link libraries

**Before:**

```cmake
target_link_libraries(${PROJECT_NAME} PRIVATE
    HailoRT::libhailort
    Threads::Threads
    ${OpenCV_LIBS}
    yaml-cpp
    CURL::libcurl
)
```

**After:**

```cmake
target_link_libraries(${PROJECT_NAME} PRIVATE
    HailoRT::libhailort
    Threads::Threads
    ${OpenCV_LIBS}
    yaml-cpp
    CURL::libcurl
    ${RPLIDAR_LIB}
    gpiod
)
```

`${RPLIDAR_LIB}` expands to the full path of the pre-built static library.
`gpiod` links the system `libgpiod` shared library.

---

## Regenerating the Makefile

After saving `CMakeLists.txt`, CMake must be re-run from the build directory:

```bash
cd hailo_apps/cpp/object_detection/build/aarch64
cmake ../..
```

CMake re-evaluates the glob, discovers the three new `.cpp` files, incorporates the
new include paths and link libraries, and writes a fresh `Makefile`.

---

## Verification

After regeneration, the following command confirms all expected translation units are
registered:

```bash
grep -o "object_detection.dir/[^ ]*\.cpp" \
  CMakeFiles/object_detection.dir/build.make | sort -u
```

Output:

```
object_detection.dir/home/maker/hailo-apps/hailo_apps/cpp/common/hailo_infer.cpp
object_detection.dir/home/maker/hailo-apps/hailo_apps/cpp/common/resources_manager.cpp
object_detection.dir/home/maker/hailo-apps/hailo_apps/cpp/common/toolbox.cpp
object_detection.dir/object_detection.cpp
object_detection.dir/rasp_gpio.cpp
object_detection.dir/RPLidar_S2L.cpp
object_detection.dir/spike.cpp
object_detection.dir/utils/utils.cpp
```

`rasp_gpio.cpp`, `RPLidar_S2L.cpp`, and `spike.cpp` are now part of the build.

---

## Building

```bash
cd hailo_apps/cpp/object_detection/build/aarch64
make -j$(nproc)
```

The resulting executable is placed in the build directory as `object_detection`.

---

## Rule for Future New Files

- **`.cpp` files** dropped into `object_detection/` are picked up automatically by the
  existing glob — just re-run `cmake ../..` from the build directory.
- **New external libraries** (headers + link targets) must be declared in
  `CMakeLists.txt` under `target_include_directories` and `target_link_libraries`
  before re-running CMake.
- **Never edit** `build/aarch64/Makefile` directly.

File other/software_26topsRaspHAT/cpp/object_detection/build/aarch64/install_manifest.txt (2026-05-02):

/usr/local/share/man/man3/curl_easy_cleanup.3
/usr/local/share/man/man3/curl_easy_duphandle.3
/usr/local/share/man/man3/curl_easy_escape.3
/usr/local/share/man/man3/curl_easy_getinfo.3
/usr/local/share/man/man3/curl_easy_header.3
/usr/local/share/man/man3/curl_easy_init.3
/usr/local/share/man/man3/curl_easy_nextheader.3
/usr/local/share/man/man3/curl_easy_option_by_id.3
/usr/local/share/man/man3/curl_easy_option_by_name.3
/usr/local/share/man/man3/curl_easy_option_next.3
/usr/local/share/man/man3/curl_easy_pause.3
/usr/local/share/man/man3/curl_easy_perform.3
/usr/local/share/man/man3/curl_easy_recv.3
/usr/local/share/man/man3/curl_easy_reset.3
/usr/local/share/man/man3/curl_easy_send.3
/usr/local/share/man/man3/curl_easy_setopt.3
/usr/local/share/man/man3/curl_easy_ssls_export.3
/usr/local/share/man/man3/curl_easy_ssls_import.3
/usr/local/share/man/man3/curl_easy_strerror.3
/usr/local/share/man/man3/curl_easy_unescape.3
/usr/local/share/man/man3/curl_easy_upkeep.3
/usr/local/share/man/man3/curl_escape.3
/usr/local/share/man/man3/curl_formadd.3
/usr/local/share/man/man3/curl_formfree.3
/usr/local/share/man/man3/curl_formget.3
/usr/local/share/man/man3/curl_free.3
/usr/local/share/man/man3/curl_getdate.3
/usr/local/share/man/man3/curl_getenv.3
/usr/local/share/man/man3/curl_global_cleanup.3
/usr/local/share/man/man3/curl_global_init.3
/usr/local/share/man/man3/curl_global_init_mem.3
/usr/local/share/man/man3/curl_global_sslset.3
/usr/local/share/man/man3/curl_global_trace.3
/usr/local/share/man/man3/curl_mime_addpart.3
/usr/local/share/man/man3/curl_mime_data.3
/usr/local/share/man/man3/curl_mime_data_cb.3
/usr/local/share/man/man3/curl_mime_encoder.3
/usr/local/share/man/man3/curl_mime_filedata.3
/usr/local/share/man/man3/curl_mime_filename.3
/usr/local/share/man/man3/curl_mime_free.3
/usr/local/share/man/man3/curl_mime_headers.3
/usr/local/share/man/man3/curl_mime_init.3
/usr/local/share/man/man3/curl_mime_name.3
/usr/local/share/man/man3/curl_mime_subparts.3
/usr/local/share/man/man3/curl_mime_type.3
/usr/local/share/man/man3/curl_mprintf.3
/usr/local/share/man/man3/curl_multi_add_handle.3
/usr/local/share/man/man3/curl_multi_assign.3
/usr/local/share/man/man3/curl_multi_cleanup.3
/usr/local/share/man/man3/curl_multi_fdset.3
/usr/local/share/man/man3/curl_multi_get_handles.3
/usr/local/share/man/man3/curl_multi_get_offt.3
/usr/local/share/man/man3/curl_multi_info_read.3
/usr/local/share/man/man3/curl_multi_init.3
/usr/local/share/man/man3/curl_multi_notify_disable.3
/usr/local/share/man/man3/curl_multi_notify_enable.3
/usr/local/share/man/man3/curl_multi_perform.3
/usr/local/share/man/man3/curl_multi_poll.3
/usr/local/share/man/man3/curl_multi_remove_handle.3
/usr/local/share/man/man3/curl_multi_setopt.3
/usr/local/share/man/man3/curl_multi_socket.3
/usr/local/share/man/man3/curl_multi_socket_action.3
/usr/local/share/man/man3/curl_multi_socket_all.3
/usr/local/share/man/man3/curl_multi_strerror.3
/usr/local/share/man/man3/curl_multi_timeout.3
/usr/local/share/man/man3/curl_multi_wait.3
/usr/local/share/man/man3/curl_multi_waitfds.3
/usr/local/share/man/man3/curl_multi_wakeup.3
/usr/local/share/man/man3/curl_pushheader_byname.3
/usr/local/share/man/man3/curl_pushheader_bynum.3
/usr/local/share/man/man3/curl_share_cleanup.3
/usr/local/share/man/man3/curl_share_init.3
/usr/local/share/man/man3/curl_share_setopt.3
/usr/local/share/man/man3/curl_share_strerror.3
/usr/local/share/man/man3/curl_slist_append.3
/usr/local/share/man/man3/curl_slist_free_all.3
/usr/local/share/man/man3/curl_strequal.3
/usr/local/share/man/man3/curl_strnequal.3
/usr/local/share/man/man3/curl_unescape.3
/usr/local/share/man/man3/curl_url.3
/usr/local/share/man/man3/curl_url_cleanup.3
/usr/local/share/man/man3/curl_url_dup.3
/usr/local/share/man/man3/curl_url_get.3
/usr/local/share/man/man3/curl_url_set.3
/usr/local/share/man/man3/curl_url_strerror.3
/usr/local/share/man/man3/curl_version.3
/usr/local/share/man/man3/curl_version_info.3
/usr/local/share/man/man3/curl_ws_meta.3
/usr/local/share/man/man3/curl_ws_recv.3
/usr/local/share/man/man3/curl_ws_send.3
/usr/local/share/man/man3/curl_ws_start_frame.3
/usr/local/share/man/man3/libcurl-easy.3
/usr/local/share/man/man3/libcurl-env-dbg.3
/usr/local/share/man/man3/libcurl-env.3
/usr/local/share/man/man3/libcurl-errors.3
/usr/local/share/man/man3/libcurl-multi.3
/usr/local/share/man/man3/libcurl-security.3
/usr/local/share/man/man3/libcurl-share.3
/usr/local/share/man/man3/libcurl-symbols.3
/usr/local/share/man/man3/libcurl-thread.3
/usr/local/share/man/man3/libcurl-tutorial.3
/usr/local/share/man/man3/libcurl-url.3
/usr/local/share/man/man3/libcurl-ws.3
/usr/local/share/man/man3/libcurl.3
/usr/local/share/man/man3/CURLINFO_ACTIVESOCKET.3
/usr/local/share/man/man3/CURLINFO_APPCONNECT_TIME.3
/usr/local/share/man/man3/CURLINFO_APPCONNECT_TIME_T.3
/usr/local/share/man/man3/CURLINFO_CAINFO.3
/usr/local/share/man/man3/CURLINFO_CAPATH.3
/usr/local/share/man/man3/CURLINFO_CERTINFO.3
/usr/local/share/man/man3/CURLINFO_CONDITION_UNMET.3
/usr/local/share/man/man3/CURLINFO_CONNECT_TIME.3
/usr/local/share/man/man3/CURLINFO_CONN_ID.3
/usr/local/share/man/man3/CURLINFO_CONNECT_TIME_T.3
/usr/local/share/man/man3/CURLINFO_CONTENT_LENGTH_DOWNLOAD.3
/usr/local/share/man/man3/CURLINFO_CONTENT_LENGTH_DOWNLOAD_T.3
/usr/local/share/man/man3/CURLINFO_CONTENT_LENGTH_UPLOAD.3
/usr/local/share/man/man3/CURLINFO_CONTENT_LENGTH_UPLOAD_T.3
/usr/local/share/man/man3/CURLINFO_CONTENT_TYPE.3
/usr/local/share/man/man3/CURLINFO_COOKIELIST.3
/usr/local/share/man/man3/CURLINFO_EARLYDATA_SENT_T.3
/usr/local/share/man/man3/CURLINFO_EFFECTIVE_METHOD.3
/usr/local/share/man/man3/CURLINFO_EFFECTIVE_URL.3
/usr/local/share/man/man3/CURLINFO_FILETIME.3
/usr/local/share/man/man3/CURLINFO_FILETIME_T.3
/usr/local/share/man/man3/CURLINFO_FTP_ENTRY_PATH.3
/usr/local/share/man/man3/CURLINFO_HEADER_SIZE.3
/usr/local/share/man/man3/CURLINFO_HTTP_CONNECTCODE.3
/usr/local/share/man/man3/CURLINFO_HTTP_VERSION.3
/usr/local/share/man/man3/CURLINFO_HTTPAUTH_AVAIL.3
/usr/local/share/man/man3/CURLINFO_HTTPAUTH_USED.3
/usr/local/share/man/man3/CURLINFO_LASTSOCKET.3
/usr/local/share/man/man3/CURLINFO_LOCAL_IP.3
/usr/local/share/man/man3/CURLINFO_LOCAL_PORT.3
/usr/local/share/man/man3/CURLINFO_NAMELOOKUP_TIME.3
/usr/local/share/man/man3/CURLINFO_NAMELOOKUP_TIME_T.3
/usr/local/share/man/man3/CURLINFO_NUM_CONNECTS.3
/usr/local/share/man/man3/CURLINFO_OS_ERRNO.3
/usr/local/share/man/man3/CURLINFO_PRETRANSFER_TIME.3
/usr/local/share/man/man3/CURLINFO_PRETRANSFER_TIME_T.3
/usr/local/share/man/man3/CURLINFO_POSTTRANSFER_TIME_T.3
/usr/local/share/man/man3/CURLINFO_PRIMARY_IP.3
/usr/local/share/man/man3/CURLINFO_PRIMARY_PORT.3
/usr/local/share/man/man3/CURLINFO_PRIVATE.3
/usr/local/share/man/man3/CURLINFO_PROTOCOL.3
/usr/local/share/man/man3/CURLINFO_PROXY_ERROR.3
/usr/local/share/man/man3/CURLINFO_PROXY_SSL_VERIFYRESULT.3
/usr/local/share/man/man3/CURLINFO_PROXYAUTH_AVAIL.3
/usr/local/share/man/man3/CURLINFO_PROXYAUTH_USED.3
/usr/local/share/man/man3/CURLINFO_QUEUE_TIME_T.3
/usr/local/share/man/man3/CURLINFO_REDIRECT_COUNT.3
/usr/local/share/man/man3/CURLINFO_REDIRECT_TIME.3
/usr/local/share/man/man3/CURLINFO_REDIRECT_TIME_T.3
/usr/local/share/man/man3/CURLINFO_REDIRECT_URL.3
/usr/local/share/man/man3/CURLINFO_REFERER.3
/usr/local/share/man/man3/CURLINFO_REQUEST_SIZE.3
/usr/local/share/man/man3/CURLINFO_RESPONSE_CODE.3
/usr/local/share/man/man3/CURLINFO_RETRY_AFTER.3
/usr/local/share/man/man3/CURLINFO_RTSP_CLIENT_CSEQ.3
/usr/local/share/man/man3/CURLINFO_RTSP_CSEQ_RECV.3
/usr/local/share/man/man3/CURLINFO_RTSP_SERVER_CSEQ.3
/usr/local/share/man/man3/CURLINFO_RTSP_SESSION_ID.3
/usr/local/share/man/man3/CURLINFO_SCHEME.3
/usr/local/share/man/man3/CURLINFO_SIZE_DELIVERED.3
/usr/local/share/man/man3/CURLINFO_SIZE_DOWNLOAD.3
/usr/local/share/man/man3/CURLINFO_SIZE_DOWNLOAD_T.3
/usr/local/share/man/man3/CURLINFO_SIZE_UPLOAD.3
/usr/local/share/man/man3/CURLINFO_SIZE_UPLOAD_T.3
/usr/local/share/man/man3/CURLINFO_SPEED_DOWNLOAD.3
/usr/local/share/man/man3/CURLINFO_SPEED_DOWNLOAD_T.3
/usr/local/share/man/man3/CURLINFO_SPEED_UPLOAD.3
/usr/local/share/man/man3/CURLINFO_SPEED_UPLOAD_T.3
/usr/local/share/man/man3/CURLINFO_SSL_ENGINES.3
/usr/local/share/man/man3/CURLINFO_SSL_VERIFYRESULT.3
/usr/local/share/man/man3/CURLINFO_STARTTRANSFER_TIME.3
/usr/local/share/man/man3/CURLINFO_STARTTRANSFER_TIME_T.3
/usr/local/share/man/man3/CURLINFO_TLS_SESSION.3
/usr/local/share/man/man3/CURLINFO_TLS_SSL_PTR.3
/usr/local/share/man/man3/CURLINFO_TOTAL_TIME.3
/usr/local/share/man/man3/CURLINFO_TOTAL_TIME_T.3
/usr/local/share/man/man3/CURLINFO_USED_PROXY.3
/usr/local/share/man/man3/CURLINFO_XFER_ID.3
/usr/local/share/man/man3/CURLMINFO_XFERS_ADDED.3
/usr/local/share/man/man3/CURLMINFO_XFERS_CURRENT.3
/usr/local/share/man/man3/CURLMINFO_XFERS_DONE.3
/usr/local/share/man/man3/CURLMINFO_XFERS_PENDING.3
/usr/local/share/man/man3/CURLMINFO_XFERS_RUNNING.3
/usr/local/share/man/man3/CURLMOPT_CHUNK_LENGTH_PENALTY_SIZE.3
/usr/local/share/man/man3/CURLMOPT_CONTENT_LENGTH_PENALTY_SIZE.3
/usr/local/share/man/man3/CURLMOPT_MAX_CONCURRENT_STREAMS.3
/usr/local/share/man/man3/CURLMOPT_MAX_HOST_CONNECTIONS.3
/usr/local/share/man/man3/CURLMOPT_MAX_PIPELINE_LENGTH.3
/usr/local/share/man/man3/CURLMOPT_MAX_TOTAL_CONNECTIONS.3
/usr/local/share/man/man3/CURLMOPT_MAXCONNECTS.3
/usr/local/share/man/man3/CURLMOPT_NETWORK_CHANGED.3
/usr/local/share/man/man3/CURLMOPT_NOTIFYDATA.3
/usr/local/share/man/man3/CURLMOPT_NOTIFYFUNCTION.3
/usr/local/share/man/man3/CURLMOPT_PIPELINING.3
/usr/local/share/man/man3/CURLMOPT_PIPELINING_SERVER_BL.3
/usr/local/share/man/man3/CURLMOPT_PIPELINING_SITE_BL.3
/usr/local/share/man/man3/CURLMOPT_PUSHDATA.3
/usr/local/share/man/man3/CURLMOPT_PUSHFUNCTION.3
/usr/local/share/man/man3/CURLMOPT_QUICK_EXIT.3
/usr/local/share/man/man3/CURLMOPT_RESOLVE_THREADS_MAX.3
/usr/local/share/man/man3/CURLMOPT_SOCKETDATA.3
/usr/local/share/man/man3/CURLMOPT_SOCKETFUNCTION.3
/usr/local/share/man/man3/CURLMOPT_TIMERDATA.3
/usr/local/share/man/man3/CURLMOPT_TIMERFUNCTION.3
/usr/local/share/man/man3/CURLOPT_ABSTRACT_UNIX_SOCKET.3
/usr/local/share/man/man3/CURLOPT_ACCEPT_ENCODING.3
/usr/local/share/man/man3/CURLOPT_ACCEPTTIMEOUT_MS.3
/usr/local/share/man/man3/CURLOPT_ADDRESS_SCOPE.3
/usr/local/share/man/man3/CURLOPT_ALTSVC.3
/usr/local/share/man/man3/CURLOPT_ALTSVC_CTRL.3
/usr/local/share/man/man3/CURLOPT_APPEND.3
/usr/local/share/man/man3/CURLOPT_AUTOREFERER.3
/usr/local/share/man/man3/CURLOPT_AWS_SIGV4.3
/usr/local/share/man/man3/CURLOPT_BUFFERSIZE.3
/usr/local/share/man/man3/CURLOPT_CAINFO.3
/usr/local/share/man/man3/CURLOPT_CAINFO_BLOB.3
/usr/local/share/man/man3/CURLOPT_CAPATH.3
/usr/local/share/man/man3/CURLOPT_CA_CACHE_TIMEOUT.3
/usr/local/share/man/man3/CURLOPT_CERTINFO.3
/usr/local/share/man/man3/CURLOPT_CHUNK_BGN_FUNCTION.3
/usr/local/share/man/man3/CURLOPT_CHUNK_DATA.3
/usr/local/share/man/man3/CURLOPT_CHUNK_END_FUNCTION.3
/usr/local/share/man/man3/CURLOPT_CLOSESOCKETDATA.3
/usr/local/share/man/man3/CURLOPT_CLOSESOCKETFUNCTION.3
/usr/local/share/man/man3/CURLOPT_CONNECT_ONLY.3
/usr/local/share/man/man3/CURLOPT_CONNECT_TO.3
/usr/local/share/man/man3/CURLOPT_CONNECTTIMEOUT.3
/usr/local/share/man/man3/CURLOPT_CONNECTTIMEOUT_MS.3
/usr/local/share/man/man3/CURLOPT_CONV_FROM_NETWORK_FUNCTION.3
/usr/local/share/man/man3/CURLOPT_CONV_FROM_UTF8_FUNCTION.3
/usr/local/share/man/man3/CURLOPT_CONV_TO_NETWORK_FUNCTION.3
/usr/local/share/man/man3/CURLOPT_COOKIE.3
/usr/local/share/man/man3/CURLOPT_COOKIEFILE.3
/usr/local/share/man/man3/CURLOPT_COOKIEJAR.3
/usr/local/share/man/man3/CURLOPT_COOKIELIST.3
/usr/local/share/man/man3/CURLOPT_COOKIESESSION.3
/usr/local/share/man/man3/CURLOPT_COPYPOSTFIELDS.3
/usr/local/share/man/man3/CURLOPT_CRLF.3
/usr/local/share/man/man3/CURLOPT_CRLFILE.3
/usr/local/share/man/man3/CURLOPT_CURLU.3
/usr/local/share/man/man3/CURLOPT_CUSTOMREQUEST.3
/usr/local/share/man/man3/CURLOPT_DEBUGDATA.3
/usr/local/share/man/man3/CURLOPT_DEBUGFUNCTION.3
/usr/local/share/man/man3/CURLOPT_DEFAULT_PROTOCOL.3
/usr/local/share/man/man3/CURLOPT_DIRLISTONLY.3
/usr/local/share/man/man3/CURLOPT_DISALLOW_USERNAME_IN_URL.3
/usr/local/share/man/man3/CURLOPT_DNS_CACHE_TIMEOUT.3
/usr/local/share/man/man3/CURLOPT_DNS_INTERFACE.3
/usr/local/share/man/man3/CURLOPT_DNS_LOCAL_IP4.3
/usr/local/share/man/man3/CURLOPT_DNS_LOCAL_IP6.3
/usr/local/share/man/man3/CURLOPT_DNS_SERVERS.3
/usr/local/share/man/man3/CURLOPT_DNS_SHUFFLE_ADDRESSES.3
/usr/local/share/man/man3/CURLOPT_DNS_USE_GLOBAL_CACHE.3
/usr/local/share/man/man3/CURLOPT_DOH_SSL_VERIFYHOST.3
/usr/local/share/man/man3/CURLOPT_DOH_SSL_VERIFYPEER.3
/usr/local/share/man/man3/CURLOPT_DOH_SSL_VERIFYSTATUS.3
/usr/local/share/man/man3/CURLOPT_DOH_URL.3
/usr/local/share/man/man3/CURLOPT_ECH.3
/usr/local/share/man/man3/CURLOPT_EGDSOCKET.3
/usr/local/share/man/man3/CURLOPT_ERRORBUFFER.3
/usr/local/share/man/man3/CURLOPT_EXPECT_100_TIMEOUT_MS.3
/usr/local/share/man/man3/CURLOPT_FAILONERROR.3
/usr/local/share/man/man3/CURLOPT_FILETIME.3
/usr/local/share/man/man3/CURLOPT_FNMATCH_DATA.3
/usr/local/share/man/man3/CURLOPT_FNMATCH_FUNCTION.3
/usr/local/share/man/man3/CURLOPT_FOLLOWLOCATION.3
/usr/local/share/man/man3/CURLOPT_FORBID_REUSE.3
/usr/local/share/man/man3/CURLOPT_FRESH_CONNECT.3
/usr/local/share/man/man3/CURLOPT_FTP_ACCOUNT.3
/usr/local/share/man/man3/CURLOPT_FTP_ALTERNATIVE_TO_USER.3
/usr/local/share/man/man3/CURLOPT_FTP_CREATE_MISSING_DIRS.3
/usr/local/share/man/man3/CURLOPT_FTP_FILEMETHOD.3
/usr/local/share/man/man3/CURLOPT_FTP_SKIP_PASV_IP.3
/usr/local/share/man/man3/CURLOPT_FTP_SSL_CCC.3
/usr/local/share/man/man3/CURLOPT_FTP_USE_EPRT.3
/usr/local/share/man/man3/CURLOPT_FTP_USE_EPSV.3
/usr/local/share/man/man3/CURLOPT_FTP_USE_PRET.3
/usr/local/share/man/man3/CURLOPT_FTPPORT.3
/usr/local/share/man/man3/CURLOPT_FTPSSLAUTH.3
/usr/local/share/man/man3/CURLOPT_GSSAPI_DELEGATION.3
/usr/local/share/man/man3/CURLOPT_HAPPY_EYEBALLS_TIMEOUT_MS.3
/usr/local/share/man/man3/CURLOPT_HAPROXYPROTOCOL.3
/usr/local/share/man/man3/CURLOPT_HAPROXY_CLIENT_IP.3
/usr/local/share/man/man3/CURLOPT_HEADER.3
/usr/local/share/man/man3/CURLOPT_HEADERDATA.3
/usr/local/share/man/man3/CURLOPT_HEADERFUNCTION.3
/usr/local/share/man/man3/CURLOPT_HEADEROPT.3
/usr/local/share/man/man3/CURLOPT_HSTS.3
/usr/local/share/man/man3/CURLOPT_HSTS_CTRL.3
/usr/local/share/man/man3/CURLOPT_HSTSREADDATA.3
/usr/local/share/man/man3/CURLOPT_HSTSREADFUNCTION.3
/usr/local/share/man/man3/CURLOPT_HSTSWRITEDATA.3
/usr/local/share/man/man3/CURLOPT_HSTSWRITEFUNCTION.3
/usr/local/share/man/man3/CURLOPT_HTTP09_ALLOWED.3
/usr/local/share/man/man3/CURLOPT_HTTP200ALIASES.3
/usr/local/share/man/man3/CURLOPT_HTTP_CONTENT_DECODING.3
/usr/local/share/man/man3/CURLOPT_HTTP_TRANSFER_DECODING.3
/usr/local/share/man/man3/CURLOPT_HTTP_VERSION.3
/usr/local/share/man/man3/CURLOPT_HTTPAUTH.3
/usr/local/share/man/man3/CURLOPT_HTTPGET.3
/usr/local/share/man/man3/CURLOPT_HTTPHEADER.3
/usr/local/share/man/man3/CURLOPT_HTTPPOST.3
/usr/local/share/man/man3/CURLOPT_HTTPPROXYTUNNEL.3
/usr/local/share/man/man3/CURLOPT_IGNORE_CONTENT_LENGTH.3
/usr/local/share/man/man3/CURLOPT_INFILESIZE.3
/usr/local/share/man/man3/CURLOPT_INFILESIZE_LARGE.3
/usr/local/share/man/man3/CURLOPT_INTERFACE.3
/usr/local/share/man/man3/CURLOPT_INTERLEAVEDATA.3
/usr/local/share/man/man3/CURLOPT_INTERLEAVEFUNCTION.3
/usr/local/share/man/man3/CURLOPT_IOCTLDATA.3
/usr/local/share/man/man3/CURLOPT_IOCTLFUNCTION.3
/usr/local/share/man/man3/CURLOPT_IPRESOLVE.3
/usr/local/share/man/man3/CURLOPT_ISSUERCERT.3
/usr/local/share/man/man3/CURLOPT_ISSUERCERT_BLOB.3
/usr/local/share/man/man3/CURLOPT_KEEP_SENDING_ON_ERROR.3
/usr/local/share/man/man3/CURLOPT_KEYPASSWD.3
/usr/local/share/man/man3/CURLOPT_KRBLEVEL.3
/usr/local/share/man/man3/CURLOPT_LOCALPORT.3
/usr/local/share/man/man3/CURLOPT_LOCALPORTRANGE.3
/usr/local/share/man/man3/CURLOPT_LOGIN_OPTIONS.3
/usr/local/share/man/man3/CURLOPT_LOW_SPEED_LIMIT.3
/usr/local/share/man/man3/CURLOPT_LOW_SPEED_TIME.3
/usr/local/share/man/man3/CURLOPT_MAIL_AUTH.3
/usr/local/share/man/man3/CURLOPT_MAIL_FROM.3
/usr/local/share/man/man3/CURLOPT_MAIL_RCPT.3
/usr/local/share/man/man3/CURLOPT_MAIL_RCPT_ALLOWFAILS.3
/usr/local/share/man/man3/CURLOPT_MAX_RECV_SPEED_LARGE.3
/usr/local/share/man/man3/CURLOPT_MAX_SEND_SPEED_LARGE.3
/usr/local/share/man/man3/CURLOPT_MAXAGE_CONN.3
/usr/local/share/man/man3/CURLOPT_MAXCONNECTS.3
/usr/local/share/man/man3/CURLOPT_MAXFILESIZE.3
/usr/local/share/man/man3/CURLOPT_MAXFILESIZE_LARGE.3
/usr/local/share/man/man3/CURLOPT_MAXLIFETIME_CONN.3
/usr/local/share/man/man3/CURLOPT_MAXREDIRS.3
/usr/local/share/man/man3/CURLOPT_MIME_OPTIONS.3
/usr/local/share/man/man3/CURLOPT_MIMEPOST.3
/usr/local/share/man/man3/CURLOPT_NETRC.3
/usr/local/share/man/man3/CURLOPT_NETRC_FILE.3
/usr/local/share/man/man3/CURLOPT_NEW_DIRECTORY_PERMS.3
/usr/local/share/man/man3/CURLOPT_NEW_FILE_PERMS.3
/usr/local/share/man/man3/CURLOPT_NOBODY.3
/usr/local/share/man/man3/CURLOPT_NOPROGRESS.3
/usr/local/share/man/man3/CURLOPT_NOPROXY.3
/usr/local/share/man/man3/CURLOPT_NOSIGNAL.3
/usr/local/share/man/man3/CURLOPT_OPENSOCKETDATA.3
/usr/local/share/man/man3/CURLOPT_OPENSOCKETFUNCTION.3
/usr/local/share/man/man3/CURLOPT_PASSWORD.3
/usr/local/share/man/man3/CURLOPT_PATH_AS_IS.3
/usr/local/share/man/man3/CURLOPT_PINNEDPUBLICKEY.3
/usr/local/share/man/man3/CURLOPT_PIPEWAIT.3
/usr/local/share/man/man3/CURLOPT_PORT.3
/usr/local/share/man/man3/CURLOPT_POST.3
/usr/local/share/man/man3/CURLOPT_POSTFIELDS.3
/usr/local/share/man/man3/CURLOPT_POSTFIELDSIZE.3
/usr/local/share/man/man3/CURLOPT_POSTFIELDSIZE_LARGE.3
/usr/local/share/man/man3/CURLOPT_POSTQUOTE.3
/usr/local/share/man/man3/CURLOPT_POSTREDIR.3
/usr/local/share/man/man3/CURLOPT_PRE_PROXY.3
/usr/local/share/man/man3/CURLOPT_PREQUOTE.3
/usr/local/share/man/man3/CURLOPT_PREREQDATA.3
/usr/local/share/man/man3/CURLOPT_PREREQFUNCTION.3
/usr/local/share/man/man3/CURLOPT_PRIVATE.3
/usr/local/share/man/man3/CURLOPT_PROGRESSDATA.3
/usr/local/share/man/man3/CURLOPT_PROGRESSFUNCTION.3
/usr/local/share/man/man3/CURLOPT_PROTOCOLS.3
/usr/local/share/man/man3/CURLOPT_PROTOCOLS_STR.3
/usr/local/share/man/man3/CURLOPT_PROXY.3
/usr/local/share/man/man3/CURLOPT_PROXY_CAINFO.3
/usr/local/share/man/man3/CURLOPT_PROXY_CAINFO_BLOB.3
/usr/local/share/man/man3/CURLOPT_PROXY_CAPATH.3
/usr/local/share/man/man3/CURLOPT_PROXY_CRLFILE.3
/usr/local/share/man/man3/CURLOPT_PROXY_ISSUERCERT.3
/usr/local/share/man/man3/CURLOPT_PROXY_ISSUERCERT_BLOB.3
/usr/local/share/man/man3/CURLOPT_PROXY_KEYPASSWD.3
/usr/local/share/man/man3/CURLOPT_PROXY_PINNEDPUBLICKEY.3
/usr/local/share/man/man3/CURLOPT_PROXY_SERVICE_NAME.3
/usr/local/share/man/man3/CURLOPT_PROXY_SSL_CIPHER_LIST.3
/usr/local/share/man/man3/CURLOPT_PROXY_SSL_OPTIONS.3
/usr/local/share/man/man3/CURLOPT_PROXY_SSL_VERIFYHOST.3
/usr/local/share/man/man3/CURLOPT_PROXY_SSL_VERIFYPEER.3
/usr/local/share/man/man3/CURLOPT_PROXY_SSLCERT.3
/usr/local/share/man/man3/CURLOPT_PROXY_SSLCERT_BLOB.3
/usr/local/share/man/man3/CURLOPT_PROXY_SSLCERTTYPE.3
/usr/local/share/man/man3/CURLOPT_PROXY_SSLKEY.3
/usr/local/share/man/man3/CURLOPT_PROXY_SSLKEY_BLOB.3
/usr/local/share/man/man3/CURLOPT_PROXY_SSLKEYTYPE.3
/usr/local/share/man/man3/CURLOPT_PROXY_SSLVERSION.3
/usr/local/share/man/man3/CURLOPT_PROXY_TLS13_CIPHERS.3
/usr/local/share/man/man3/CURLOPT_PROXY_TLSAUTH_PASSWORD.3
/usr/local/share/man/man3/CURLOPT_PROXY_TLSAUTH_TYPE.3
/usr/local/share/man/man3/CURLOPT_PROXY_TLSAUTH_USERNAME.3
/usr/local/share/man/man3/CURLOPT_PROXY_TRANSFER_MODE.3
/usr/local/share/man/man3/CURLOPT_PROXYAUTH.3
/usr/local/share/man/man3/CURLOPT_PROXYHEADER.3
/usr/local/share/man/man3/CURLOPT_PROXYPASSWORD.3
/usr/local/share/man/man3/CURLOPT_PROXYPORT.3
/usr/local/share/man/man3/CURLOPT_PROXYTYPE.3
/usr/local/share/man/man3/CURLOPT_PROXYUSERNAME.3
/usr/local/share/man/man3/CURLOPT_PROXYUSERPWD.3
/usr/local/share/man/man3/CURLOPT_PUT.3
/usr/local/share/man/man3/CURLOPT_QUICK_EXIT.3
/usr/local/share/man/man3/CURLOPT_QUOTE.3
/usr/local/share/man/man3/CURLOPT_RANDOM_FILE.3
/usr/local/share/man/man3/CURLOPT_RANGE.3
/usr/local/share/man/man3/CURLOPT_READDATA.3
/usr/local/share/man/man3/CURLOPT_READFUNCTION.3
/usr/local/share/man/man3/CURLOPT_REDIR_PROTOCOLS.3
/usr/local/share/man/man3/CURLOPT_REDIR_PROTOCOLS_STR.3
/usr/local/share/man/man3/CURLOPT_REFERER.3
/usr/local/share/man/man3/CURLOPT_REQUEST_TARGET.3
/usr/local/share/man/man3/CURLOPT_RESOLVE.3
/usr/local/share/man/man3/CURLOPT_RESOLVER_START_DATA.3
/usr/local/share/man/man3/CURLOPT_RESOLVER_START_FUNCTION.3
/usr/local/share/man/man3/CURLOPT_RESUME_FROM.3
/usr/local/share/man/man3/CURLOPT_RESUME_FROM_LARGE.3
/usr/local/share/man/man3/CURLOPT_RTSP_CLIENT_CSEQ.3
/usr/local/share/man/man3/CURLOPT_RTSP_REQUEST.3
/usr/local/share/man/man3/CURLOPT_RTSP_SERVER_CSEQ.3
/usr/local/share/man/man3/CURLOPT_RTSP_SESSION_ID.3
/usr/local/share/man/man3/CURLOPT_RTSP_STREAM_URI.3
/usr/local/share/man/man3/CURLOPT_RTSP_TRANSPORT.3
/usr/local/share/man/man3/CURLOPT_SASL_AUTHZID.3
/usr/local/share/man/man3/CURLOPT_SASL_IR.3
/usr/local/share/man/man3/CURLOPT_SEEKDATA.3
/usr/local/share/man/man3/CURLOPT_SEEKFUNCTION.3
/usr/local/share/man/man3/CURLOPT_SERVER_RESPONSE_TIMEOUT.3
/usr/local/share/man/man3/CURLOPT_SERVER_RESPONSE_TIMEOUT_MS.3
/usr/local/share/man/man3/CURLOPT_SERVICE_NAME.3
/usr/local/share/man/man3/CURLOPT_SHARE.3
/usr/local/share/man/man3/CURLOPT_SOCKOPTDATA.3
/usr/local/share/man/man3/CURLOPT_SOCKOPTFUNCTION.3
/usr/local/share/man/man3/CURLOPT_SOCKS5_AUTH.3
/usr/local/share/man/man3/CURLOPT_SOCKS5_GSSAPI_NEC.3
/usr/local/share/man/man3/CURLOPT_SOCKS5_GSSAPI_SERVICE.3
/usr/local/share/man/man3/CURLOPT_SSH_AUTH_TYPES.3
/usr/local/share/man/man3/CURLOPT_SSH_COMPRESSION.3
/usr/local/share/man/man3/CURLOPT_SSH_HOSTKEYDATA.3
/usr/local/share/man/man3/CURLOPT_SSH_HOSTKEYFUNCTION.3
/usr/local/share/man/man3/CURLOPT_SSH_HOST_PUBLIC_KEY_MD5.3
/usr/local/share/man/man3/CURLOPT_SSH_HOST_PUBLIC_KEY_SHA256.3
/usr/local/share/man/man3/CURLOPT_SSH_KEYDATA.3
/usr/local/share/man/man3/CURLOPT_SSH_KEYFUNCTION.3
/usr/local/share/man/man3/CURLOPT_SSH_KNOWNHOSTS.3
/usr/local/share/man/man3/CURLOPT_SSH_PRIVATE_KEYFILE.3
/usr/local/share/man/man3/CURLOPT_SSH_PUBLIC_KEYFILE.3
/usr/local/share/man/man3/CURLOPT_SSL_CIPHER_LIST.3
/usr/local/share/man/man3/CURLOPT_SSL_CTX_DATA.3
/usr/local/share/man/man3/CURLOPT_SSL_CTX_FUNCTION.3
/usr/local/share/man/man3/CURLOPT_SSL_EC_CURVES.3
/usr/local/share/man/man3/CURLOPT_SSL_ENABLE_ALPN.3
/usr/local/share/man/man3/CURLOPT_SSL_ENABLE_NPN.3
/usr/local/share/man/man3/CURLOPT_SSL_FALSESTART.3
/usr/local/share/man/man3/CURLOPT_SSL_OPTIONS.3
/usr/local/share/man/man3/CURLOPT_SSL_SESSIONID_CACHE.3
/usr/local/share/man/man3/CURLOPT_SSL_SIGNATURE_ALGORITHMS.3
/usr/local/share/man/man3/CURLOPT_SSL_VERIFYHOST.3
/usr/local/share/man/man3/CURLOPT_SSL_VERIFYPEER.3
/usr/local/share/man/man3/CURLOPT_SSL_VERIFYSTATUS.3
/usr/local/share/man/man3/CURLOPT_SSLCERT.3
/usr/local/share/man/man3/CURLOPT_SSLCERT_BLOB.3
/usr/local/share/man/man3/CURLOPT_SSLCERTTYPE.3
/usr/local/share/man/man3/CURLOPT_SSLENGINE.3
/usr/local/share/man/man3/CURLOPT_SSLENGINE_DEFAULT.3
/usr/local/share/man/man3/CURLOPT_SSLKEY.3
/usr/local/share/man/man3/CURLOPT_SSLKEY_BLOB.3
/usr/local/share/man/man3/CURLOPT_SSLKEYTYPE.3
/usr/local/share/man/man3/CURLOPT_SSLVERSION.3
/usr/local/share/man/man3/CURLOPT_STDERR.3
/usr/local/share/man/man3/CURLOPT_STREAM_DEPENDS.3
/usr/local/share/man/man3/CURLOPT_STREAM_DEPENDS_E.3
/usr/local/share/man/man3/CURLOPT_STREAM_WEIGHT.3
/usr/local/share/man/man3/CURLOPT_SUPPRESS_CONNECT_HEADERS.3
/usr/local/share/man/man3/CURLOPT_TCP_FASTOPEN.3
/usr/local/share/man/man3/CURLOPT_TCP_KEEPALIVE.3
/usr/local/share/man/man3/CURLOPT_TCP_KEEPIDLE.3
/usr/local/share/man/man3/CURLOPT_TCP_KEEPINTVL.3
/usr/local/share/man/man3/CURLOPT_TCP_KEEPCNT.3
/usr/local/share/man/man3/CURLOPT_TCP_NODELAY.3
/usr/local/share/man/man3/CURLOPT_TELNETOPTIONS.3
/usr/local/share/man/man3/CURLOPT_TFTP_BLKSIZE.3
/usr/local/share/man/man3/CURLOPT_TFTP_NO_OPTIONS.3
/usr/local/share/man/man3/CURLOPT_TIMECONDITION.3
/usr/local/share/man/man3/CURLOPT_TIMEOUT.3
/usr/local/share/man/man3/CURLOPT_TIMEOUT_MS.3
/usr/local/share/man/man3/CURLOPT_TIMEVALUE.3
/usr/local/share/man/man3/CURLOPT_TIMEVALUE_LARGE.3
/usr/local/share/man/man3/CURLOPT_TLS13_CIPHERS.3
/usr/local/share/man/man3/CURLOPT_TLSAUTH_PASSWORD.3
/usr/local/share/man/man3/CURLOPT_TLSAUTH_TYPE.3
/usr/local/share/man/man3/CURLOPT_TLSAUTH_USERNAME.3
/usr/local/share/man/man3/CURLOPT_TRAILERDATA.3
/usr/local/share/man/man3/CURLOPT_TRAILERFUNCTION.3
/usr/local/share/man/man3/CURLOPT_TRANSFER_ENCODING.3
/usr/local/share/man/man3/CURLOPT_TRANSFERTEXT.3
/usr/local/share/man/man3/CURLOPT_UNIX_SOCKET_PATH.3
/usr/local/share/man/man3/CURLOPT_UNRESTRICTED_AUTH.3
/usr/local/share/man/man3/CURLOPT_UPKEEP_INTERVAL_MS.3
/usr/local/share/man/man3/CURLOPT_UPLOAD.3
/usr/local/share/man/man3/CURLOPT_UPLOAD_BUFFERSIZE.3
/usr/local/share/man/man3/CURLOPT_UPLOAD_FLAGS.3
/usr/local/share/man/man3/CURLOPT_URL.3
/usr/local/share/man/man3/CURLOPT_USE_SSL.3
/usr/local/share/man/man3/CURLOPT_USERAGENT.3
/usr/local/share/man/man3/CURLOPT_USERNAME.3
/usr/local/share/man/man3/CURLOPT_USERPWD.3
/usr/local/share/man/man3/CURLOPT_VERBOSE.3
/usr/local/share/man/man3/CURLOPT_WILDCARDMATCH.3
/usr/local/share/man/man3/CURLOPT_WRITEDATA.3
/usr/local/share/man/man3/CURLOPT_WRITEFUNCTION.3
/usr/local/share/man/man3/CURLOPT_WS_OPTIONS.3
/usr/local/share/man/man3/CURLOPT_XFERINFODATA.3
/usr/local/share/man/man3/CURLOPT_XFERINFOFUNCTION.3
/usr/local/share/man/man3/CURLOPT_XOAUTH2_BEARER.3
/usr/local/share/man/man3/CURLSHOPT_LOCKFUNC.3
/usr/local/share/man/man3/CURLSHOPT_SHARE.3
/usr/local/share/man/man3/CURLSHOPT_UNLOCKFUNC.3
/usr/local/share/man/man3/CURLSHOPT_UNSHARE.3
/usr/local/share/man/man3/CURLSHOPT_USERDATA.3
/usr/local/share/man/man1/curl-config.1
/usr/local/share/man/man1/wcurl.1
/usr/local/share/man/man1/runtests.1
/usr/local/share/man/man1/testcurl.1
/usr/local/lib/libcurl.a
/usr/local/bin/curl-config
/usr/local/lib/pkgconfig/libcurl.pc
/usr/local/include/curl/system.h
/usr/local/include/curl/header.h
/usr/local/include/curl/easy.h
/usr/local/include/curl/curl.h
/usr/local/include/curl/curlver.h
/usr/local/include/curl/stdcheaders.h
/usr/local/include/curl/multi.h
/usr/local/include/curl/options.h
/usr/local/include/curl/typecheck-gcc.h
/usr/local/include/curl/websockets.h
/usr/local/include/curl/mprintf.h
/usr/local/include/curl/urlapi.h
/usr/local/lib/cmake/CURL/CURLTargets.cmake
/usr/local/lib/cmake/CURL/CURLTargets-noconfig.cmake
/usr/local/lib/cmake/CURL/CURLConfigVersion.cmake
/usr/local/lib/cmake/CURL/CURLConfig.cmake
/usr/local/lib/cmake/CURL/FindBrotli.cmake
/usr/local/lib/cmake/CURL/FindCares.cmake
/usr/local/lib/cmake/CURL/FindGSS.cmake
/usr/local/lib/cmake/CURL/FindGnuTLS.cmake
/usr/local/lib/cmake/CURL/FindLDAP.cmake
/usr/local/lib/cmake/CURL/FindLibbacktrace.cmake
/usr/local/lib/cmake/CURL/FindLibgsasl.cmake
/usr/local/lib/cmake/CURL/FindLibidn2.cmake
/usr/local/lib/cmake/CURL/FindLibpsl.cmake
/usr/local/lib/cmake/CURL/FindLibssh.cmake
/usr/local/lib/cmake/CURL/FindLibssh2.cmake
/usr/local/lib/cmake/CURL/FindLibuv.cmake
/usr/local/lib/cmake/CURL/FindMbedTLS.cmake
/usr/local/lib/cmake/CURL/FindNGHTTP2.cmake
/usr/local/lib/cmake/CURL/FindNGHTTP3.cmake
/usr/local/lib/cmake/CURL/FindNGTCP2.cmake
/usr/local/lib/cmake/CURL/FindNettle.cmake
/usr/local/lib/cmake/CURL/FindQuiche.cmake
/usr/local/lib/cmake/CURL/FindRustls.cmake
/usr/local/lib/cmake/CURL/FindWolfSSL.cmake
/usr/local/lib/cmake/CURL/FindZstd.cmake
/usr/local/bin/wcurl

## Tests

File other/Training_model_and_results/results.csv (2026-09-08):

epoch | time | train/box_loss | train/cls_loss | train/dfl_loss | metrics/precision(B) | metrics/recall(B) | metrics/mAP50(B) | metrics/mAP50-95(B) | val/box_loss | val/cls_loss | val/dfl_loss | lr/pg0 | lr/pg1 | lr/pg2
1 | 14.3448 | 0.99816 | 2.76167 | 0.86785 | 0.0118 | 0.96752 | 0.46185 | 0.31603 | 0.84816 | 2.86665 | 0.79608 | 0.00040008 | 0.00040008 | 0.00040008
2 | 21.8684 | 0.86458 | 0.95344 | 0.83838 | 0.98441 | 0.18214 | 0.92916 | 0.72293 | 0.72474 | 2.27625 | 0.80914 | 0.000808743 | 0.000808743 | 0.000808743
3 | 29.8027 | 0.82016 | 0.71651 | 0.8488 | 0.97182 | 0.51013 | 0.94409 | 0.74509 | 0.72285 | 1.69575 | 0.80412 | 0.00120916 | 0.00120916 | 0.00120916
4 | 36.9994 | 0.81513 | 0.6769 | 0.84204 | 0.9847 | 0.9604 | 0.97959 | 0.77395 | 0.71852 | 1.01235 | 0.80415 | 0.00160132 | 0.00160132 | 0.00160132
5 | 44.0337 | 0.77581 | 0.63459 | 0.83924 | 0.9898 | 0.97832 | 0.98133 | 0.80298 | 0.62616 | 0.61397 | 0.79588 | 0.00160099 | 0.00160099 | 0.00160099
6 | 50.6757 | 0.7533 | 0.60321 | 0.82902 | 0.98299 | 0.97991 | 0.98233 | 0.80655 | 0.62755 | 0.49996 | 0.79624 | 0.00158448 | 0.00158448 | 0.00158448
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

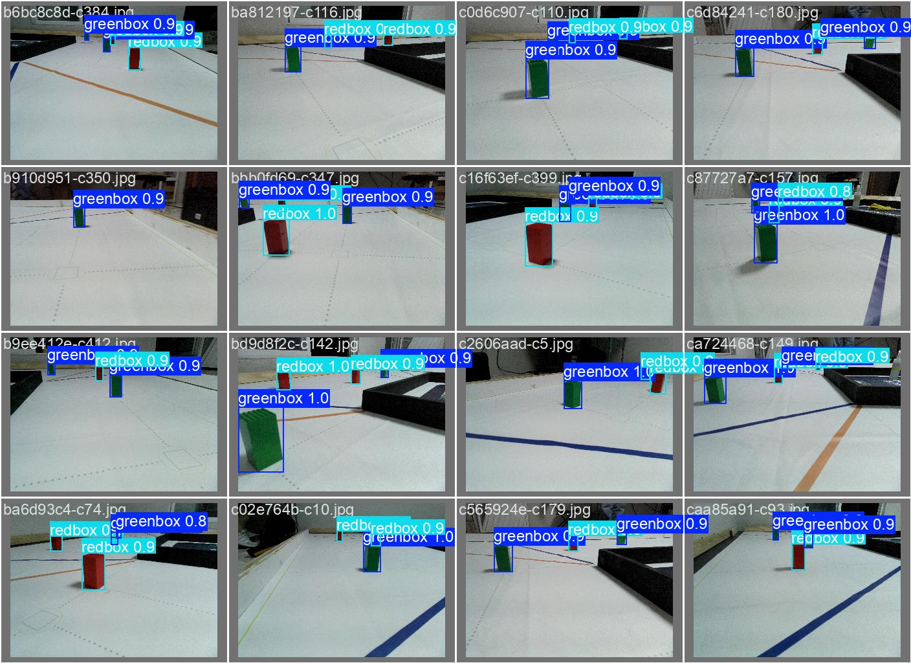
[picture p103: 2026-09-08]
other/Training_model_and_results/val_batch2_pred.jpg

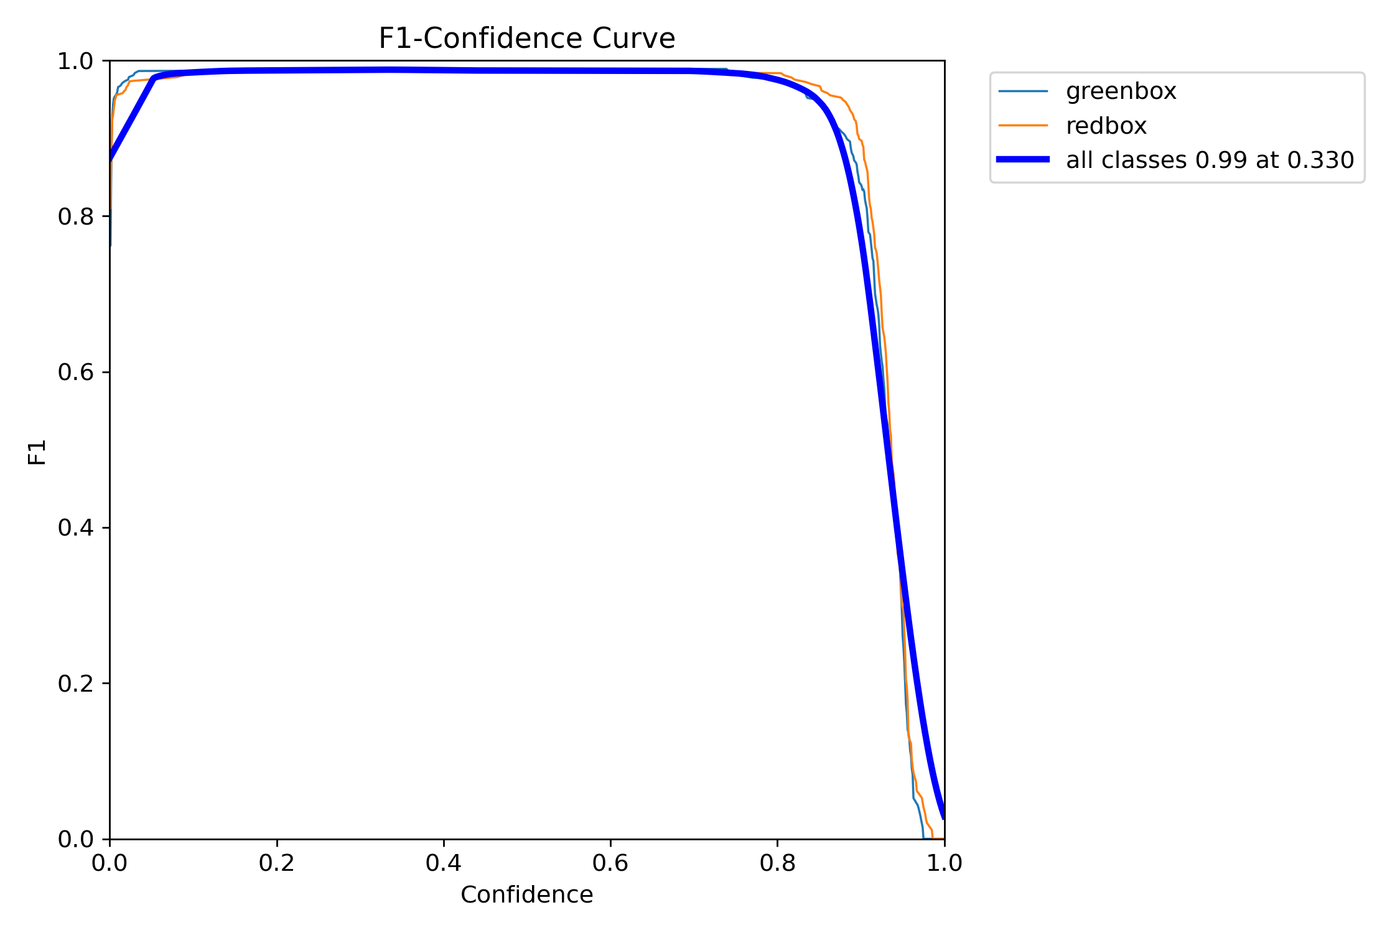
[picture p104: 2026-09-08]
other/Training_model_and_results/F1_curve.png

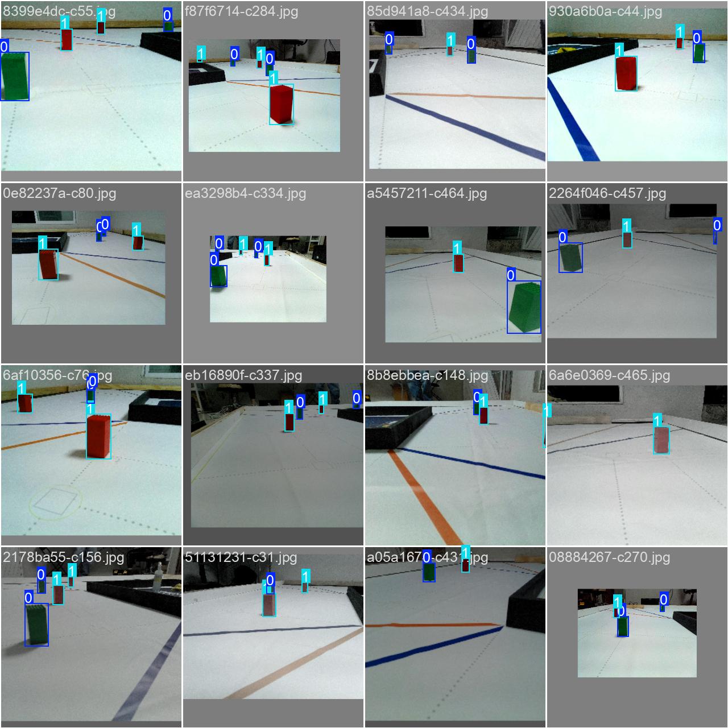
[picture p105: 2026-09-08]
other/Training_model_and_results/train_batch2252.jpg

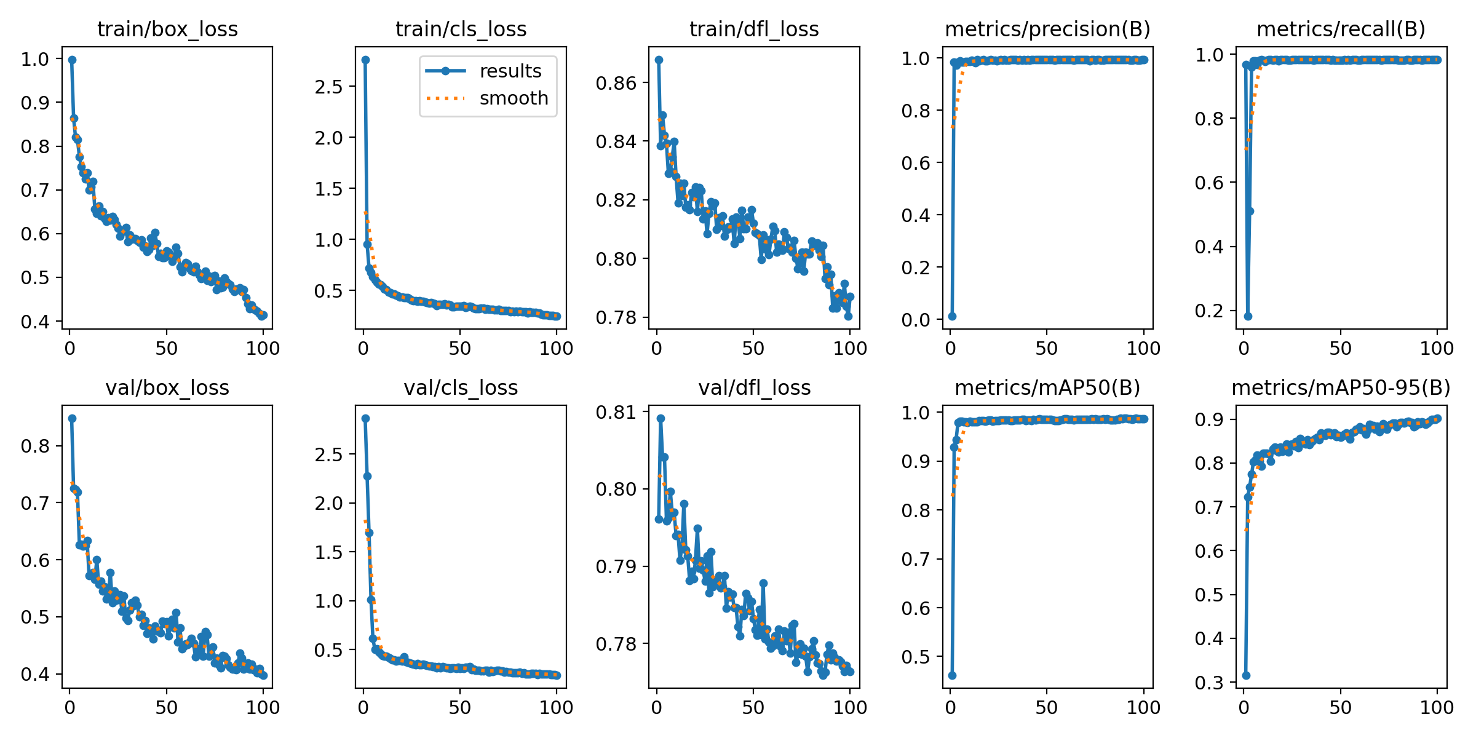
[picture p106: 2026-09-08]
other/Training_model_and_results/results.png

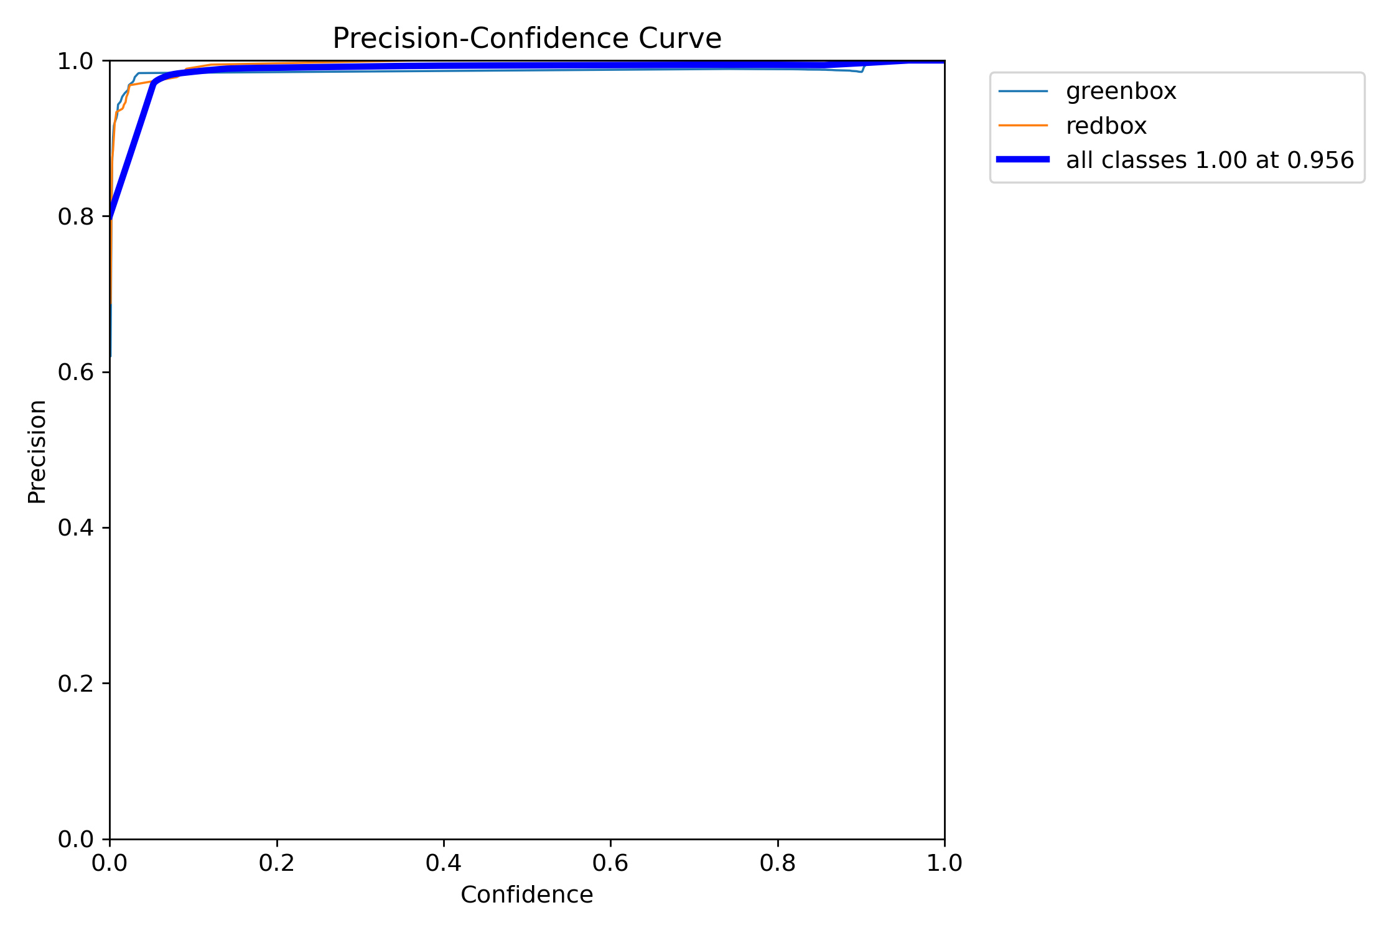
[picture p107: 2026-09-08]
other/Training_model_and_results/P_curve.png

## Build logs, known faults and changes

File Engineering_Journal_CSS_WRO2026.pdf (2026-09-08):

## ENGINEERING JOURNAL

# Team CSS

## WRO Future Engineers 2026

Queretaro, Mexico

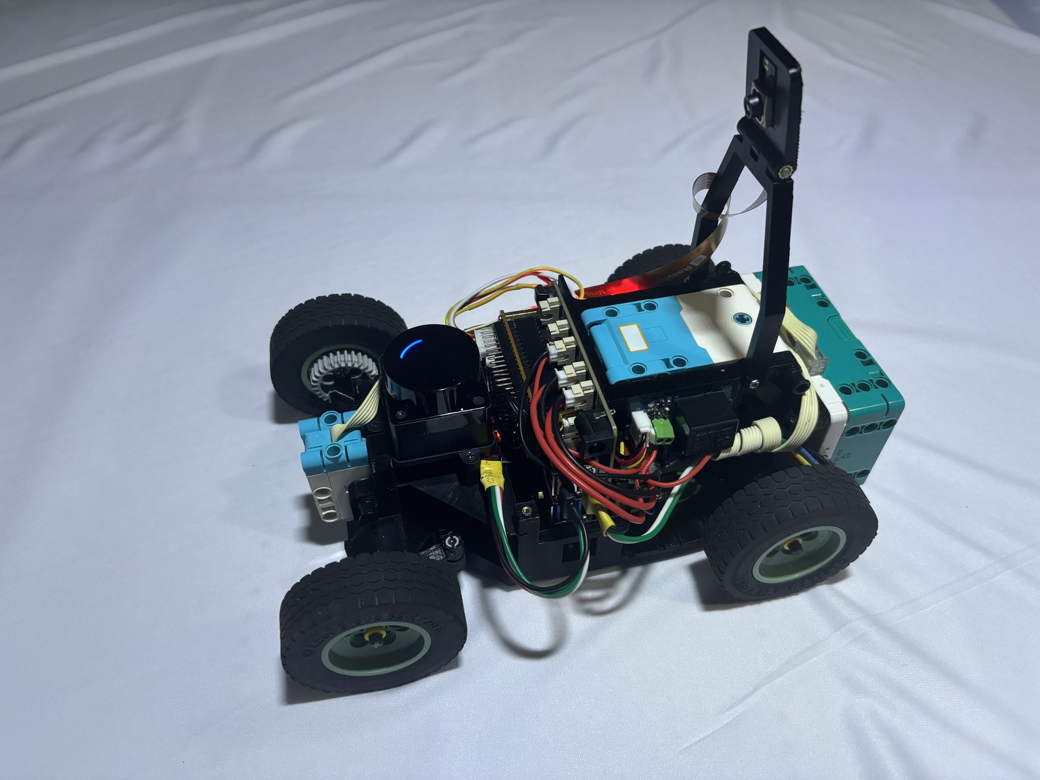
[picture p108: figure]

The 2026 competition vehicle, "The Maker" (design v6)

Vehicle | "The Maker"
Team members | Christian Gael Centeno Velez (Captain) · Sebastian Esquivel Mondragon
Coach | Manuel Alejandro Cardoso Duarte
Dimensions / Mass | 240 × 160 × 250 mm · 1.006 kg
Drive / Steering | Rear-wheel drive, single axle · Front Ackermann, 45.44° max
Compute | Raspberry Pi 5 + Hailo-10H AI HAT+ · LEGO SPIKE Prime Hub
Repository | github.com/alex309-duarte/WRO_Future_Engineers_Queretaro_CSS

Engineering Journal | Team CSS | WRO Future Engineers 2026
Vehicle: "The Maker" | Queretaro, Mexico | Page 2

# How to read this journal

This journal is organised around the five evaluation criteria in Appendix C of the 2026 Future Engineers rules, so that each criterion has an obvious home:

Rubric criterion | Where it is addressed
1. Mobility and Mechanical Design | Section 2 - steering, drivetrain, motor sizing, chassis, design evolution
2. Power and Sensor Architecture | Section 3 - power budget, failures, sensor selection, placement, calibration
3. Software Architecture and Obstacle Strategy | Section 4 - threading, perception, control, both challenge strategies, vision
model
4. Systems Thinking and Engineering Decisions | Section 5 - tradeoff register, risk register, subsystem coupling
5. Reproducibility and GitHub Quality | Section 7 - repository map, interfaces, physical specification
Section 6 is the dated logbook that ties them together. Every constant quoted in this journal is the value actually present in the source code in our public repository, not a design target.

# 1. Design philosophy and season constraints

We did not start this season from a blank page. We finished the 2025 season with a working Future Engineers vehicle that placed 2nd nationally, and our starting decision was whether to iterate on it or rebuild. We chose to keep the concept - Ackermann-steered, LiDAR-led, LEGO SPIKE actuation - and rebuild everything else, because our post-season review identified three problems that were structural rather than tuning issues:
– Latency. The 2025 codebase was Python. Adding a higher-rate camera and LiDAR made the control loop the bottleneck, not the sensors.
– Mass and packaging. The 2025 vehicle came in barely under the 1.5 kg limit, with a high centre of gravity and loosely packaged electronics. Being that close to a hard rule limit is itself a design risk - it means any late addition is impossible.
– Mechanical inconsistency. The custom double-Ackermann steering we built in 2025 gave a tighter turning radius but did not behave the same way twice.

Those findings became the season's design goals: cut latency, cut mass, and trade peak capability for repeatability wherever the two conflict. That last principle explains most of the decisions in this journal, including several where we deliberately chose the less capable option.

### Constraints we designed against

Constraint | Source | Limit | Our value | How it shaped the design

Maximum
dimensions

Rule 11.1 300 × 200 × 300
mm

240 × 160 × 250
mm

Dense electronics packaging; ultrasonics removed

Maximum mass | Rule 11.2 | 1.5 kg | 1.006 kg (67%) | Down from barely under 1.5 kg in 2025

One driving axle,
one | steering
actuator
Rule 11.3 | - | RWD | + | front
Ackermann

Ruled out the 2025 AWD layout

No wireless during
rounds
Rule 11.10 - | Radios disabled,
Ethernet only

See Section 5.2

Track wall height | Game field 100 mm | LiDAR at 60-80
mm

Hard constraint - see Section 3.4

Round time limit Rules 9.1 /
9.2
3 minutes | - | Sets minimum viable average speed for 3 laps
Parking lot length | Game field 1.5 × vehicle
length
360 mm bay | Shorter vehicle means a proportionally shorter bay

Constraint | Source | Limit | Our value | How it shaped the design
Budget | Team | - | $33,018.73 MXN | Ruled out a second accelerator and a spare vehicle

The mass figure deserves emphasis. Going from barely under 1.5 kg to 1.006 kg did not just buy compliance margin - it is the root cause of half the changes in Section 2. A lighter vehicle needs less steering torque, which permitted a smaller steering motor, which returned mass and volume, which permitted denser packaging. We return to that chain in Section 5.3, including the part where it went wrong.

Note also the interaction in the parking row, which we did not anticipate at the start of the season: the parking bay is defined as 1.5× our own vehicle length, so making the robot shorter makes the bay proportionally shorter too. Shrinking the chassis does not make parking easier. It holds the difficulty constant while shrinking our margin for error in absolute millimetres.

# 2. Mobility and mechanical design

### 2.1 Steering: why we went backwards on purpose

In 2025 we designed and built a custom double-Ackermann linkage - both axles steering - to get a tighter turning radius. It worked, and on a good run it was better than a conventional layout. The problem was that it was not consistent: the additional linkage introduced play, and the steering did not return to the same neutral point reliably across runs.

For 2026 we replaced it with a regular Ackermann linkage steering the front axle only, reaching a maximum steer angle of 45.44°.

We chose regular Ackermann instead of double-Ackermann because the double-Ackermann's advantage was a smaller turning radius, but our failure mode was never "the corner was too tight to make" - it was "the robot did not end the corner pointing where we expected." The regular Ackermann completes every turn the WRO track requires with margin, and it removes a mechanical error source from every corner of a 12-corner run. We traded a capability we did not need for a consistency we did.

The Ackermann condition - inner and outer wheels tracing concentric arcs about a common centre - is what keeps the front tyres rolling instead of scrubbing. This matters twice over: scrubbing costs traction mid-corner, and it makes the effective wheelbase behave differently at different steer angles, which is exactly the non-repeatability we were trying to design out.

Actuator change. Steering is driven by a LEGO SPIKE Small Angular Motor (45607), replacing the Medium Angular Motor used previously. This was a consequence of the mass reduction, not an independent choice: with a lighter chassis the required steering torque dropped enough that the smaller motor became sufficient, which then returned both mass and packaging volume.

### 2.2 Drivetrain: AWD to RWD

The 2025 vehicle was all-wheel drive. The 2026 vehicle is rear-wheel drive.

We chose RWD instead of AWD because AWD required a front differential and driveshaft to carry torque past the steering axle. That hardware cost mass, volume in exactly the region where the Ackermann linkage lives, and one more set of mechanical tolerances. On a flat, high-grip competition mat the traction AWD buys is not the limiting factor - our lap times are limited by cornering confidence, not wheelspin. Paired with the LEGO 62.4 × 20 S rubber tyres, the single driven rear axle has not slipped in testing.

### 2.3 Motor sizing: the calculation we did before buying anything

We sized the traction motor against a dynamic torque budget rather than picking a motor and hoping. Target: reach cruising speed in t = 0.5 s, implying a = 0.73 m/s²
Parameter | Symbol | Value
Vehicle mass | m | 1.006 kg
Wheel radius | r | 0.0312 m
Target acceleration | a | 0.73 m/s²
Rolling resistance coefficient | Crr | 0.03
Gear reduction (20:28) | R | 1.4
Gearbox efficiency | eta | 0.85

Derivation.
– Acceleration force: F
acc

= m·a = 0.7344 N

– Rolling resistance: F
rr

= Crr

·m·g = 0.2961 N
– Total: Ftotal = 1.0305 N – Wheel torque: T
w

= Ftotal·r = 0.03215 N·m
– Motor torque: T
m

= T
w

/ (eta·R) = 0.02702 N·m (2.70 N·cm) – With a 1.25× margin: T
m,req

= 0.03377 N·m (3.38 N·cm)

Result against the LEGO Large Angular Motor (45602) - max-efficiency point 8.00 N·cm at 135 rpm, stall torque 25.00 N·cm:

Metric | Value | Interpretation
Load vs. max-efficiency torque | 33.8% | Motor runs well inside its efficient band
Load vs. stall torque | 10.8% | No realistic stall risk
Loaded top speed | 0.365 m/s | Reached in 0.5 s at the design acceleration
Torque reserve | 66.2% | Absorbs perturbations without dropping speed

Running at a third of the motor's efficient capacity is not conservatism for its own sake: a motor near its limit changes speed when the load changes, and a robot whose speed depends on how hard the last corner was is a robot whose distance-based manoeuvres drift.

### 2.4 Chassis and centre of gravity

The chassis is a fully custom design, modelled in SolidWorks and printed on a Creality K1C. The 2026 revision repackages the electronics much more densely and moves the battery pack, the Raspberry Pi 5, the UPS board and the LiDAR lower in the frame.

The objective was lateral weight transfer. In a corner, transfer scales with CG height; less transfer keeps the inside front wheel loaded, which keeps the Ackermann geometry doing what it was designed to do instead of being defeated by an unloaded tyre. This was the mechanical half of the same "repeatability over peak capability" theme as Section 2.1.

### 2.5 Design evolution: six vehicles in two seasons

Our current chassis is the sixth distinct design the team has built across two seasons. Listing them matters because the 2026 vehicle is not an incremental descendant of the 2025 one - there is a deliberate discontinuity between v2 and v3.

2025 season - v1 and v2

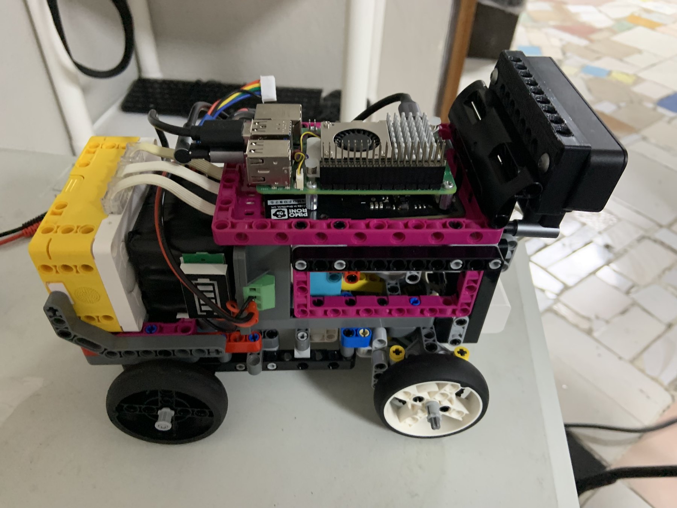
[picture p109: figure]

v1 - hybrid LEGO Technic chassis, regional competition (Queretaro). Yellow SPIKE Prime hub, Raspberry Pi on a Technic deck, OAK-D Lite camera at the front. Our first Future Engineers vehicle was built partly from LEGO Technic structural elements. The advantage was speed of iteration: we could change the geometry in an afternoon without waiting on a printer. The limitation is visible in the photograph - component placement is dictated by the Technic hole grid rather than by what the vehicle needs, the electronics sit high above the axles, and the assembly has play at every beam connection.

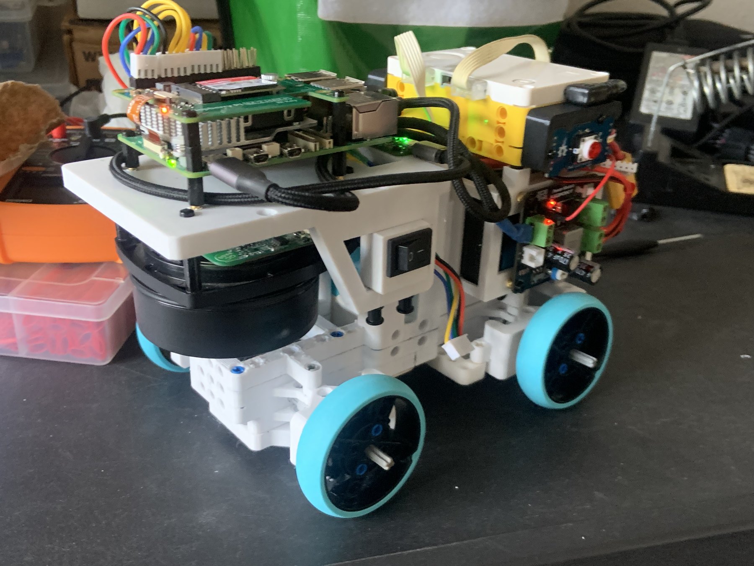
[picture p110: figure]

v2 - fully custom 3D-printed chassis, national competition (2nd place nationally). RPLidar S2L on the front deck, double-Ackermann steering, AWD.
For the national competition we abandoned the Technic structure and designed a fully custom, 3D-printed chassis. This removed the grid constraint and the accumulated joint play, and it is the design that carried the double-Ackermann steering and the AWD drivetrain to 2nd place nationally. Its weaknesses are the three findings listed in Section 1: heavy (barely under 1.5 kg), high centre of gravity, and mechanically inconsistent steering. Note in the photograph how much vertical stack there is above the wheels - that is the CG problem we set out to fix.

2026 season - a clean-sheet redesign, then four iterations (v3 to v6)

For 2026 we did not modify v2. We started a complete redesign, because the changes we wanted - lower CG, different steering geometry, RWD, denser packaging - were not reachable by editing the previous frame. That redesign then went through four iterations, each a focused improvement on the one before.

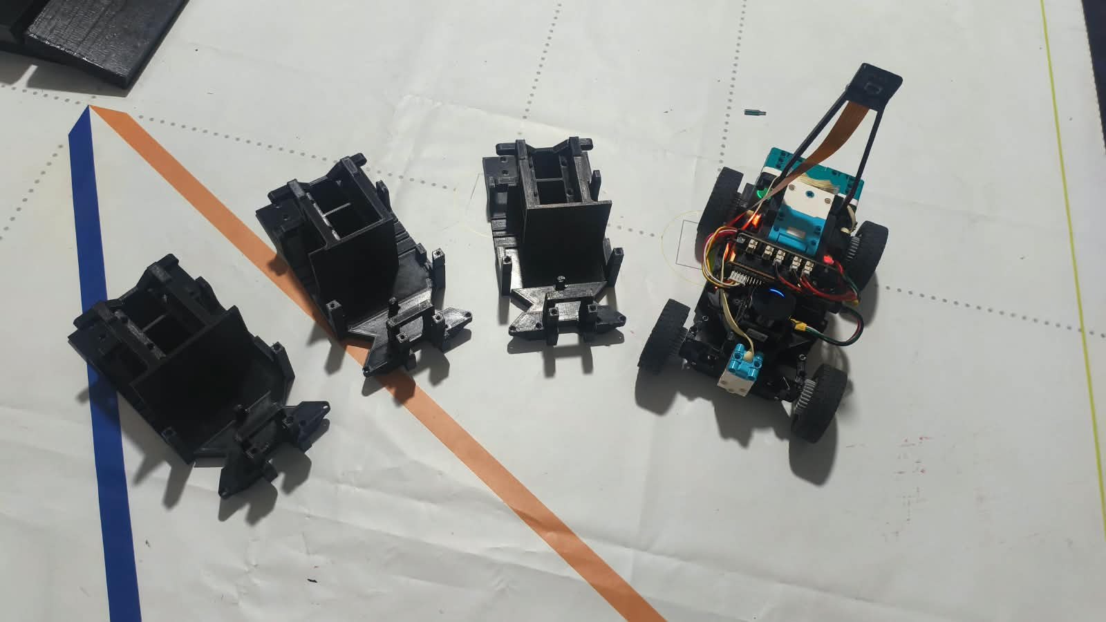
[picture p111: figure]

The 2026 iterations side by side: v3, v4 and v5 as bare printed frames, with v6 assembled at the right. The progression from left to right is visible in the frame itself - material removed, mounting features consolidated, and the central bay opened up to drop the electronics lower.

# | Iteration | Focus of this revision

v3 | 2026 clean sheet | New layout: RWD, regular Ackermann, battery and Pi dropped low in the frame
v4 | Packaging | Component placement tightened around the new layout
v5 | Mounting | Mounting and serviceability fixes, including the LiDAR mount revision of Section 3.4
v6 | Final | Final geometry and mounting; the vehicle documented throughout this journal

We chose a clean-sheet redesign instead of iterating v2 because the three problems we had were all layout problems. Lowering the CG means moving the battery and the Pi, which means moving everything around them; changing from double- to single-Ackermann changes the front axle entirely; dropping AWD removes the front driveshaft that the old frame was built around. Each change individually might have been retrofittable. Together they left almost nothing of the original frame, so retrofitting would have cost more than starting over and produced a worse result - a frame carrying mounting features for hardware that no longer existed.

The distinction between the two seasons is worth stating plainly, because it is the shape of our engineering process: 2025 to 2026 was a discontinuity driven by structural problems; within 2026, progress was incremental. Once the layout was right, no iteration after v3 changed the concept - v4 through v6 are refinements of packaging, mounting and serviceability. Knowing which mode you are in matters: retrofitting a broken layout wastes time, and clean-sheeting a working one throws away tuning.

# 3. Power and sensor architecture

### 3.1 Power budget

Storage. 4 × Panasonic NCR18650B (3400 mAh, 3.6 V nominal) in a 2S2P arrangement - two series stages of two parallel cells - giving 7.2 V nominal, 6800 mAh, 48.96 Wh. The pack feeds a Geekworm X1203 UPS/boost board that supplies the 5.1 V the Raspberry Pi 5 and its peripherals require.

This replaces the 2025 pack, which was the same 2-series topology with three cells per stage - 2S3P, six cells, 10200 mAh. We reduced the pack by one third.

We chose 4 cells instead of 6 because the 2025 pack was sized for a load we no longer have. Lighter, more efficient components (Section 3.5) cut the draw, and the endurance calculation below shows even the smaller pack runs for hours against a 3-minute round. Two cells of capacity we were never going to use cost mass we could not spare, on a vehicle that was already barely inside the 1.5 kg limit. This is the clearest case this season of removing capability because the requirement went away.

Component | State | Power
Raspberry Pi 5 | High CPU / OS load | 9.0 W
Hailo-10H AI HAT | Continuous neural network inference | 4.0 W
Oradar MS200k LiDAR | Scanning, motor spinning | 1.5 W
Grove modules | Relay pulses + LED button | 0.1 W
Total at 5.1 V | | 14.6 W

Accounting for the X1203's ~90% conversion efficiency:
– Pinput = 14.6 / 0.90 = 16.22 W
– Pack current at 7.2 V = 2.25 A
– Per parallel branch: 1.13 A per cell

That per-cell figure is the one that matters. The NCR18650B is rated for 4.8 A continuous, so we are at roughly a quarter of it - which keeps the cells out of the thermal region where internal resistance climbs, and is precisely the failure we hit in Section 3.2.

Theoretical worst-case endurance: 48.96 Wh / 16.22 W = 3.0 hours.

Measured reality. On the bench the integrated system draws 0.667 A per connector - each connector being one parallel pair - totalling 1.334 A at 5 V = 6.67 W, or 7.41 W at the pack. That gives 6.6 hours of continuous running. The gap between 3.0 and 6.6 hours is simply that sustained simultaneous peak CPU and peak inference load does not occur in a real 3-minute round.

Known limitation. The cells charge in place through the X1203. Swapping in a charged set requires partially disassembling the chassis, so a depleted robot has to be plugged in rather than hot-swapped. Against a 6.6-hour endurance and a 3-minute round this is not a competition risk, but it does limit how much testing we can do away from mains power, and we would design a removable tray if we rebuilt this.

### 3.2 Failure: brownouts under acceleration

Symptom. With the Raspberry Pi 5 and the Hailo accelerator both active, the system would shut down abruptly during hard acceleration - not gradually, not with a warning, just off.

Investigation. The pack still showed plenty of charge, ruling out simple depletion. The correlation with acceleration pointed at a transient: the traction motor's current spike was pulling the rail down far enough to reset the Pi. We were using generic 18650 cells, and generic cells have high internal resistance - under a current spike the terminal voltage sags in proportion to that resistance.

Fix. Two changes together: Panasonic NCR18650B cells, which hold a much flatter discharge curve under load, and the X1203 board, which both regulates and buffers the rail. The brownouts stopped completely and have not recurred.

What we took from it. A power system is not specified by capacity alone. Our original selection criterion was mAh, which is the wrong criterion for a load with sharp transients; internal resistance and discharge-curve flatness were what actually mattered. This is the clearest example this season of a component that met its stated spec and still failed the application.

### 3.3 LiDAR: RPLidar S2L to Oradar MS200k

Problem. During early testing the RPLidar S2L returned distorted and imprecise readings specifically when the vehicle passed very close to a track wall - exactly the condition our wall-following logic depends on most, and exactly when a bad reading is most expensive.

Decision. We replaced it with the Orbbec Oradar MS200k, whose optics and internal firmware handle ultra-short-range reflections much more cleanly. It is also lighter, serving the season's mass goal.

We chose the MS200k instead of keeping the S2L because the S2L's noise was worst in the operating region we actually live in. A sensor that is accurate at 2 m and unreliable at 15 cm is the wrong sensor for a robot whose job is to hug a wall.

The driver switch is still visible in the codebase: src/ondevice/ builds against either driver via a compile-time switch (make LIDAR=oradar selects the Oradar path; plain make still defaults to the legacy RPLidar driver).

### 3.4 Failure: the LiDAR could not see the walls

This is the most instructive failure of our season, because the mechanical design and the sensor requirement were developed separately and only met on the track.

Symptom. After finishing the new compact chassis, the robot behaved as though it were blind - it was not detecting the track walls at all.

Cause. The compact repackaging had placed the LiDAR high in the frame. The track walls are 100 mm tall. The LiDAR's scanning plane was passing over them. Every wall reading was a miss, not a bad measurement - the mounting geometry had silently invalidated the entire perception stack.

Fix. We iterated the central CAD mount to bring the LiDAR down to roughly 60-80 mm above the floor, safely inside the wall height. The non-obvious part was that lowering it put it level with the rear chassis structure, so the same revision had to keep the rear field of view clear - a 360° sensor with a structural blind spot behind it would have broken the rear-distance readings the parking manoeuvre depends on.

What we took from it. Sensor placement is a constraint imposed by the field, not a packaging variable to be optimised freely. We now treat the 100 mm wall height as a hard design input alongside the 300 × 200 × 300 mm envelope, and any future chassis revision is checked against it before it is printed rather than after.

### 3.5 Vision: OAK-D Lite to Camera Module 3 Wide + Hailo-10H

The 2025 vehicle used an OAK-D Lite, an integrated stereo camera with onboard inference (visible on v1 and v2 in Section 2.5). For 2026 we split the job into a Raspberry Pi Camera Module 3 Wide for capture and a Raspberry Pi AI HAT+ (Hailo-10H, 40 TOPS) for inference.

We chose the split camera + accelerator instead of the integrated OAK-D Lite because it was lighter, drew less power, and inferred faster - three of the season's goals at once. The cost is a more complex software stack: we now own the whole capture, preprocess, infer and postprocess pipeline rather than receiving finished detections from an integrated device. We judged that acceptable because owning the pipeline is also what let us train and deploy our own model (Section 4.8) instead of working within a vendor's toolchain.

### 3.6 What we removed: ultrasonic sensors

Previous seasons carried ultrasonic rangefinders. The 2026 vehicle has none. Once the MS200k proved reliable at short range (Section 3.3), the ultrasonics were measuring something the LiDAR already measured better, while costing mass, power, GPIO pins and mounting volume in a chassis we were actively trying to shrink. Removing a working sensor is uncomfortable, but a redundant sensor that nothing reads is just ballast.

### 3.7 Sensor placement and calibration

Item | Setting | Rationale
LiDAR height | 60-80 mm above floor | Below the 100 mm wall height - see Section 3.4
ORADAR_ANGLE_OFFS ET | 270° | Empirically determined for this chassis's LiDAR mounting orientation; only needs re-checking if the mount rotates
Gyro zero | Automatic, at the start of every run | Rule 9.9 forbids pre-start calibration, so the reset happens after the start button is pressed
Steering neutral | 45.44° max angle, fixed in hardware | No software calibration step
Chassis | self-return
rejection | Returns closer than 150 mm discarded | The robot's own body is inside the LiDAR's field of view

# 4. Software architecture and obstacle strategy

### 4.1 The migration to C/C++

Problem. The 2025 Python codebase became the bottleneck as soon as we attached a higher-rate camera and LiDAR. The sensors could supply data faster than the loop could consume it, so the robot was acting on stale information.

Decision. We rewrote the acquisition and control logic in C/C++, and spent the first weeks of the season doing nothing else. The justification was deterministic timing: when several high-rate sensor streams have to be combined at speed, garbage-collection pauses and interpreter overhead show up directly as steering jitter.

Result. The main control loop stabilised at more than 50 Hz.

We chose to rewrite instead of optimising the Python because the problem was not a slow function we could profile and fix - it was the cost of the runtime itself under multi-threaded, high-rate sensor load. Optimising would have bought a constant factor; changing language changed the ceiling. The cost was several weeks of the season producing no new capability, which is why it had to happen first or not at all.

### 4.2 Threading model

The Obstacle Challenge binary (object_detection) runs cooperating threads:
– a Hailo pipeline thread - preprocess, inference and postprocess on camera frames, keeping a global traffic_lights struct (colour, x-position, area, confidence) current;
– a LiDAR reader thread - continuously filling a 360-slot distance buffer;
– Obstacle_Challenge_Thread - the navigation state machine, which reads both and issues motor commands over serial to the SPIKE hub.

The Open Challenge is a separate, simpler binary (src/ondevice/) that never starts the camera or Hailo pipeline at all - there are no coloured pillars to detect, so loading the vision stack would only add boot time and failure surface.

### 4.3 Wall detection: Select_Wall()

Each call runs a six-stage pipeline. The constants below are the values in the source.

# | Stage | What it does

1 | Angular windowing | A 70°-wide window centred on the requested side, with the innermost ±3° excluded to avoid seam
and corner noise
2 | Chassis filtering | Returns closer than 150 mm are the robot's own body
3 | Radius | Outlier
Removal

A point is dropped with fewer than 3 neighbours within 300 mm, with 15° of padding outside the window so edge points are not unfairly penalised

4 | Segmentation | Split wherever consecutive points jump by more than 60 mm, then split again at corners by
Iterative End-Point Fit with a 40 mm deviation threshold
5 | Scoring | A segment qualifies only with at least 6 points, 200 mm end-to-end extent, and an RMS
perpendicular residual under 15 mm against its Total-Least-Squares best-fit line
6 | Per-side tracking | Once a wall is chosen for a side, later frames prefer to keep following that same physical wall
(matched within 300 mm and 20°) rather than re-snapping every frame

Total-Least-Squares (PCA) is used rather than ordinary least squares because it has no bias toward any particular wall orientation. Stage 5 earns its complexity: the 200 mm minimum extent is what rejects the 50 × 50 mm traffic-sign pillars. Without it, a pillar at the right distance reads as a wall and the robot follows an obstacle.

### 4.4 Heading estimation - and what it is not

Heading comes primarily from the SPIKE Prime Hub's built-in gyroscope, read and reset over serial. LiDAR wall-orientation readings (Slope(), Correction_For_Triangles_Left/Right) correct position and alignment at defined points in the manoeuvre logic.

We want to be precise, because it is easy to overclaim: this is not sensor fusion. There is no complementary filter, no Kalman filter, no algorithm combining the two signals into a single estimate. The honest description is gyro-primary heading with situational LiDAR-based positional correction - the gyro runs orientation continuously, and the LiDAR intervenes at known points to correct accumulated drift against a known wall.

We considered a complementary filter and did not implement one. The gyro's drift over a single 3-minute round is small, and re-squaring against a physical wall at every corner resets it to a ground truth that a filter would only have estimated. A filter would have added tuning parameters and a new failure mode to solve a problem the geometry already solved.

### 4.5 Closed-loop steering

Steering uses PD control - proportional to lateral position error, derivative to damp the oscillation pure P produces. Two separately tuned loops:

Controller | K
p

Kd

Camera-based cube following | 150 | 100
Gyro-based wall following | 2 | 300000

Both gain sets were obtained by trial-and-error tuning on the physical track, not derived analytically. We state that plainly rather than implying a model-based process. The very different magnitudes reflect the different error units the two loops work in - normalised pixel offset versus degrees of heading error.

Our tuning method was to change one gain at a time and judge the result by watching the robot's line through a section: too little D and the robot weaves down a straight, too much and it responds sluggishly to a real correction. This is a subjective process, and it is the main methodological weakness of our software work this season - see Section 8.

No integral term is used in either loop. Steady-state offset is not our failure mode, and an integrator accumulating during a cube-avoidance manoeuvre would fight the next correction.

### 4.6 Open Challenge strategy

The run is direction-agnostic: an initial LiDAR read determines which side is open (sentido), and the entire subsequent path is the sign-mirror of the other direction.

Constant | Value | Where it acts
Outside/inside start split | 800 mm | A side reading above this means an "outside" starting box
First straight (outside / inside) | 1350 / 300 mm | Distance driven after the first turn
Slope sampling gap | 300 + 700 mm | Two Slope() reads, averaged into one heading correction
Corner turn angle | 80° | Every corner turn
Corner loop | 10 iterations | Plus the setup turn and the final turn = 12 corners = 3 laps
Final approach bands | 400 / 600 mm | Selects the parking stop distance
Final front threshold | 1500 mm | Chooses a 1400 or 1750 mm stop from the front wall

Averaging two slope measurements taken 700 mm apart, rather than trusting one, is a deliberate noise-rejection step: a single bad wall fit at the start of a straight would otherwise be baked into the gyro reference for that whole section.

### 4.7 Obstacle Challenge strategy

Direction is decided once from the initial side-wall reading (600 mm split) and held for the attempt. The unit of the run is one corner cycle - Corner_Case followed by Desicion - repeated 12 times (3 laps × 4 corners), with the 4th corner of each lap run in parking mode.

Corner_Case advances to 1100 mm from the front wall, reads the pillar colour the camera currently sees, and advances a colour-dependent distance (green 600/400 mm, red 990 mm, none 650 mm) before turning 86° into the next section. Desicion then re-squares the gyro against the outer side wall and dispatches to the cube-avoidance routines, which compute an angle and hypotenuse to the detected pillar, turn toward it, pass it, and straighten.

Passing rule: green means pass on the left, red means pass on the right. This is fixed by rule 9.19 and does not mirror with the driving direction - worth stating explicitly because almost everything else in the run does mirror.

Parking. The vision model detects the magenta parking-lot markers directly, as a dedicated x-parking class alongside the two pillar classes. Detecting the markers rather than inferring the bay from wall geometry was a deliberate choice: the bay is defined relative to a dotted line and a movable magenta element, so its position is not derivable from the track walls alone. Once the markers are located, the LiDAR positions the robot at a set distance from the wall and the manoeuvre runs on combined LiDAR and gyro readings.

### 4.8 Vision model: training and measured performance

We trained our own detector rather than using a stock model, because the classes we care about - red and green traffic-sign pillars, and the magenta parking markers, under competition lighting - are not COCO classes.

Dataset. Hand-annotated by the team in YOLO format, held in other/dataset/. The pillar classes were collected first and deliberately balanced almost exactly; the x-parking class was added in a later collection pass once the parking strategy of Section 4.7 was settled.

Training configuration. YOLOv8n, 100 epochs, batch 16, image size 320, initial learning rate 0.01, on GPU. Augmentation: HSV jitter, horizontal flip (p = 0.5), mosaic with close_mosaic at 10, random erasing 0.4. Horizontal flip is safe here - a pillar is symmetric - and note it does not teach the model anything about which side to pass, since that is decided in code from the class, not from the image.

Measured results from the training run published in other/Training_model_and_results/results.csv (501 images, two pillar classes, 1,896 labelled instances balanced 947 / 949):

Metric | Epoch 1 | Epoch 100
Precision | 0.012 | 0.993
Recall | 0.968 | 0.984
mAP@50 | 0.462 | 0.986
mAP@50-95 | 0.316 | 0.902

Precision at 0.993 with recall at 0.984 is the balance we wanted. A false positive sends the robot around a pillar that is not there; a brief miss is recoverable, because the LiDAR still prevents a collision with a real obstacle. We would rather miss a frame than hallucinate one.

Note for judges: the metrics above are from the two-class training run whose full artefacts (curves, confusion matrix, weights) are published in the repository. The model deployed on the competition vehicle adds the x-parking class; its training artefacts are published alongside the updated weights.

Deployment. The .pt weights are compiled to Hailo .hef format with the Hailo Dataflow Compiler. The compiler and the on-device HailoRT runtime must both be v5.x for the Hailo-10H - the Hailo-8/8L v3.x/v4.x pairing is incompatible, and a version mismatch produces a .hef that compiles cleanly and then fails to load on the Pi. This cost us time and is written down here so it does not cost anyone else's.

# 5. Systems thinking: tradeoffs, risks and mitigations

### 5.1 Tradeoff register

# | Decision | Rejected alternative | Why | Cost accepted

1 | Regular Ackermann | Double-Ackermann
(v2)
Repeatability beat turning radius | Wider turning circle
2 | Rear-wheel drive | All-wheel drive (v2) | Traction was never the limit; AWD cost
mass and volume

Less grip in a hypothetical low-grip case

3 | Clean-sheet | 2026
frame

Retrofitting the v2
frame

All three problems were layout problems Restarted the mechanical design

4 | C/C++ | Optimising Python | Needed a higher ceiling, not a constant
factor

Weeks of season time, no
new features
5 | Oradar MS200k | RPLidar S2L | Accuracy where we operate: very close to
walls

New driver integration

6 | Camera + Hailo-10H | OAK-D Lite | Lighter, lower power, faster inference | We own the whole vision
pipeline now
7 | 4-cell 2S2P pack | 6-cell 2S3P (2025) | Load dropped; endurance still far exceeds
round length

Less reserve if consumption grows

8 | Small steering motor | Medium (2025) | Lower mass made it sufficient | Less torque headroom if
mass grows
9 | No ultrasonics | Keep as redundancy | LiDAR measured it better; mass, pins,
volume

No independent backup
range sensor
10 Gyro | + | situational
correction
Kalman | /
complementary filter

Wall re-squaring gives ground truth, not an estimate

| | | No | continuous | fused
| | | estimate
11 No integral term | Full PID | Steady-state offset is not our failure mode | Small | persistent | offsets
uncorrected
12 Vision-detected parking markers | Geometric inference from walls | Bay position is not derivable from the walls alone

Depends on the detector
seeing magenta reliably
13 Single | vehicle, | no
spare | Build two | Budget; rule 11.26 forbids a spare on the day anyway

No fallback if it breaks in
| | | transit

### 5.2 Risk and failure-mode register

Risk | How it shows up | Mitigation | Status
Gyro drift over a run | Robot ends a corner mis-aimed

Re-square against the side wall at every corner
| | (Slope, ±90°)

Mitigated in code

Pillar misread as wall | Robot | follows | an
| obstacle
200 mm minimum wall extent in Select_Wall() | Mitigated in code
LiDAR noise at very short range | Bad wall fit near a wall | Sensor change (3.3) + ROR filtering | | Mitigated
Voltage sag under load | Sudden reset mid-run | Low-ESR cells + X1203 buffering (3.2) | | Resolved
LiDAR blind to walls | Total navigation failure | Mount height fixed below 100 mm (3.4) | | Resolved
.hef / runtime version mismatch | Model fails to load at the venue

Both pinned to v5.x; documented in the README
| | setup steps

Documented

Wireless used during a
round
Disqualification | (rules
| 11.6 / 11.10)
See procedure below | Procedure defined

Risk | How it shows up | Mitigation | Status
Sensor failure mid-run | Robot continues on bad data | None implemented. No automatic fallback exists | Open, accepted
Emergency stop | - | No hardware e-stop separate from terminating the
process
| | | Open, accepted

Wireless compliance procedure. During development we work over Wi-Fi SSH, because it is far more convenient for iterating on the track. That is not permissible during a round, so at competition we switch to SSH over a wired Ethernet connection, which the team has done at previous competitions. Our documented pre-round procedure is:
– Connect to the vehicle over Ethernet for any final setup between rounds.
– Disable the Raspberry Pi's Wi-Fi and Bluetooth radios in software, and confirm the SPIKE Prime hub's Bluetooth is off.
– Physically disconnect the Ethernet cable before the round begins - rule 11.6 prohibits wired control systems while the vehicle is running, not merely wireless ones.
– Start the vehicle with the single power switch, then the single start button (rules 9.10, 9.11).

Steps 2 and 3 are the ones that are easy to forget under time pressure, which is exactly why they are written down here rather than left as team knowledge.

We list the final two rows of the table as unresolved rather than omitting them. Neither is required by the rules, and adding a second button would conflict with rule 9.11's single-start-button requirement, but a judge asking "what happens if the LiDAR dies on lap two?" deserves the honest answer: the robot keeps driving on stale data until the round ends.

### 5.3 How the subsystems constrain each other

The decisions above are not independent, and the season's most useful lesson was watching one change propagate:

Reduce mass -> steering torque drops -> smaller steering motor fits -> mass and volume freed -> denser packaging possible -> CG lowered -> less weight transfer -> Ackermann geometry stays effective -> cornering more repeatable.

In parallel: lighter and more efficient electronics -> lower current draw -> the 6-cell pack became two cells of unusable reserve -> 4-cell pack -> less mass again, feeding back into the same loop.

And simultaneously, the same denser packaging -> LiDAR pushed upward -> above the 100 mm walls -> total perception failure (Section 3.4).

The design move that produced most of our gains also produced our worst failure. That is the clearest argument we can make for why a chassis revision is now checked against the field geometry before it is printed.

# 6. Logbook

Date | Milestone | Section
2026-02-07 | Repository created; season begins. Decision to rebuild rather than iterate the 2025 vehicle | 1

2026-03-07 to 03-14 SPIKE and Raspberry Pi control functions ported to C; repository restructured to the WRO

| template layout | 4.1
2026-03-21 | KiCad schematics added; RPLidar S2L driver integrated | 3.3
2026-04-18 | Double-Ackermann reviewed against 2025 race experience; decision taken to revert to regular Ackermann for 2026 | 2.1
2026-05-09 | v3 - clean-sheet chassis: RWD, regular Ackermann, battery and Pi dropped low in the frame | 2.5
2026-05-30 | v4 - packaging refinement around the new layout | 2.5
2026-06-13 | Brownouts under acceleration diagnosed; generic cells replaced with Panasonic NCR18650B, X1203 integrated | 3.2
2026-06-27 | Battery pack reduced from 2S3P (6 cells) to 2S2P (4 cells) after re-running the power budget | 3.1
2026-07-11 | RPLidar S2L short-range noise identified; Oradar MS200k selected and driver integrated behind a compile-time switch | 3.3
2026-07-25 | LiDAR mounting-height failure found - scan plane passing above the 100 mm walls | 3.4
2026-08-01 | v5 - revised central LiDAR mount, sensor lowered to 60-80 mm, rear field of view cleared | 2.5, 3.4
2026-08-08 | OAK-D Lite replaced by Camera Module 3 Wide + Hailo-10H AI HAT | 3.5
2026-08-15 | Vision dataset labelled; YOLOv8n trained, 100 epochs, mAP@50 0.986 | 4.8
2026-08-22 | Model compiled to .hef and deployed; HailoRT / DFC v5.x version pairing resolved | 4.8
2026-08-29 | v6 (final) - final geometry and mounting; vehicle photographed | 2.5
2026-09-05 | Ultrasonic sensors removed after the MS200k proved reliable at short range | 3.6
2026-09-07 | Documentation, BOM, flowcharts and final repository organisation completed | 7

# 7. Reproducibility

Everything | needed | to | rebuild | this | vehicle | is | in | the | public | repository | at
github.com/alex309-duarte/WRO_Future_Engineers_Queretaro_CSS:
Content | Location
Control and vision source | src/
CAD - SolidWorks parts, assemblies and STEP | models/cad/New/
Printable STLs and print settings | models/cad/New/stl/
Design history photographs (v1 to v6) | models/designs/
Wiring diagram | schemes/hardware/wiringSchematics.jpeg
Training dataset and labels | other/dataset/
Training results and weights | other/Training_model_and_results/
Datasheets | other/datasheets/
Compiled models | src/HailoModels/
Build and run instructions | README.md section 8 and src/README.md

### Hardware interfaces

| Interface | | | | Port | | | Rate
SPIKE Prime hub | /dev/ttyACM0 | 115200 baud
Oradar MS200k LiDAR | /dev/ttyUSB0 | 230400 baud
Start button | GPIO 4 (BCM) | -
Status LED | GPIO 3 (BCM) | -
SPIKE power relay | GPIO 2 (BCM) | -

### Physical specification

Property | Value | Rule limit
Dimensions (L × W × H) | 240 × 160 × 250 mm | 300 × 200 × 300 mm
Mass | | | | | 1.006 kg | | | | 1.5 kg
Drive | Rear-wheel, single axle | One driving axle
Steering | Front Ackermann, 45.44° max | One steering actuator

Bill of materials: 12 line items, $33,018.73 MXN total. Full table with sourcing links in README.md section 6.

# 8. What we would do differently

– Check sensor geometry against the field before printing a chassis. Section 3.4 cost us real time and was entirely predictable from a number printed in the rules.
– Specify power by internal resistance, not capacity. Section 3.2 was a selection-criterion error, not a component failure.
– Design a removable battery tray. The in-place charging constraint limits how much testing we can do in a session away from mains power.
– Instrument the robot to log runs. This is our biggest methodological gap. Our PD tuning (Section 4.5) and our mechanical iterations (Section 2.5) were judged by watching the robot, not by measurement. Logged per-run telemetry would let us say "this change improved corner exit angle by X degrees" instead of "it felt better", and would have made this journal considerably stronger. It is the first thing we would build next season.

Team CSS - Christian Gael Centeno Velez, Sebastian Esquivel Mondragon
Coach: Manuel Alejandro Cardoso Duarte - Queretaro, Mexico - 2026 season

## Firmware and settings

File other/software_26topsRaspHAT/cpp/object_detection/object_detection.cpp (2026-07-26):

#include "toolbox.hpp"
#include "hailo_infer.hpp"
#include "utils.hpp"

#include "spike.h"
#include "rasp_gpio.h"
#include "Oradar_S2L.h"
#include "common_var.h"

struct traffic_lights_struct{
    float  middle_point_x;
    float  middle_point_y;
    int light_color; /* red = 2,  green = 1, xparking = 3 */
    float area;
    float confidence;
};

static traffic_lights_struct traffic_lights;

// Set from args.no_display in main() so postprocess_callback (which doesn't receive
// CommandLineArgs) can skip opening the lidar visualization window too.
static bool g_no_display = false;

pthread_t writer;
pthread_t Main_Actions;
static volatile int terminating_main = 0;

// segment_id -> persistent color slot for the most recently detected walls, refreshed
// every new lidar scan in postprocess_callback. Global so other code can inspect which
// color slot a given wall segment currently holds.
std::unordered_map<int, int> wall_rank;

void signal_handler(int signum);
void *Obstacle_Challenge_Thread(void *arg);
void Follow_cubes(int vel, float referencia_2, float area);
float Slope(const direction side);
float Distance_To_Wall(const direction side);
void Print_Slope(const direction side);
void Follow_Wall(const direction side);
float calculte_angle_section_start_clockwise(Color_traffic_light traffic_light_color, int cube_number_per_section);
float calculte_angle_section_start_counterclockwise(Color_traffic_light traffic_light_color, int cube_number_per_section);
static float Fit_Line_Orientation(const std::vector<cv::Point2f> &pts, const std::vector<int> &indices);
void avoid_cube_start_section(Color_traffic_light traffic_light_color, Cube_number cube_number_per_section);

// Holds the window points and the chosen wall's indices into them, shared by Slope()
// and Distance_To_Wall() so both report on exactly the same wall-selection result
// instead of independently re-running (and potentially disagreeing on) the selection.
// Defined up here (rather than next to Select_Wall's definition) so postprocess_callback
// can call Select_Wall directly to draw each side's wall independently.
struct WallSelection {
    bool found = false;
    std::vector<cv::Point2f> pts;
    std::vector<int> chosen_indices;
    std::vector<int> used_angles; // lidar angles (0-359) backing chosen_indices
};
static WallSelection Select_Wall(const direction side);

int find_max_index(float arr[], int n) {
    if (n <= 0) return -1; // Handle empty array case

    int max_index = 0;
    float max_value = arr[0];

    for (int i = 1; i < n; i++) {
        if (arr[i] > max_value) {
            max_value = arr[i];
            max_index = i;
        }
    }
    return max_index;
}

// Recursively splits a contiguous wall segment at its point of maximum perpendicular
// deviation from the straight line joining its endpoints (Iterative End-Point Fit /
// split-and-merge). This catches corners that a gap-based breakpoint detector misses:
// two walls meeting at a corner have no range discontinuity between consecutive points,
// only a change in orientation, so a pure distance-gap check sees them as one wall.
void split_segment_at_corners(const std::vector<cv::Point2f> &points_mm,
                               const std::vector<int> &indices,
                               float threshold_mm,
                               int corner_margin_points,
                               std::vector<std::vector<int>> &out_segments)
{
    if (indices.size() < 3) {
        out_segments.push_back(indices);
        return;
    }

    const cv::Point2f &p1 = points_mm[indices.front()];
    const cv::Point2f &p2 = points_mm[indices.back()];
    cv::Point2f line_dir = p2 - p1;
    float line_len = (float)cv::norm(line_dir);

    float max_dist = 0;
    size_t split_at = 0;
    for (size_t k = 1; k + 1 < indices.size(); k++) {
        const cv::Point2f &p = points_mm[indices[k]];
        float dist = (line_len < 1e-3f)
            ? (float)cv::norm(p - p1)
            : std::fabs(line_dir.cross(p - p1)) / line_len;
        if (dist > max_dist) {
            max_dist = dist;
            split_at = k;
        }
    }

    if (max_dist > threshold_mm && split_at > 0) {
        // Drop a few points straddling the corner vertex: lidar returns right at a
        // corner are noisy/transitional and otherwise tend to form their own tiny
        // spurious "wall" instead of cleanly belonging to either side.
        size_t left_end = (split_at >= (size_t)corner_margin_points) ? split_at - corner_margin_points : 0;
        size_t right_start = std::min(split_at + (size_t)corner_margin_points, indices.size() - 1);
        std::vector<int> left(indices.begin(), indices.begin() + left_end + 1);
        std::vector<int> right(indices.begin() + right_start, indices.end());
        split_segment_at_corners(points_mm, left, threshold_mm, corner_margin_points, out_segments);
        split_segment_at_corners(points_mm, right, threshold_mm, corner_margin_points, out_segments);
    } else {
        out_segments.push_back(indices);
    }
}

using namespace hailo_utils;
using Clock = std::chrono::steady_clock;

namespace fs = std::filesystem;

/////////// Constants ///////////
constexpr size_t MAX_QUEUE_SIZE = 60;

std::shared_ptr<BoundedTSQueue<std::pair<std::vector<cv::Mat>, std::vector<cv::Mat>>>> preprocessed_batch_queue =
    std::make_shared<BoundedTSQueue<std::pair<std::vector<cv::Mat>, std::vector<cv::Mat>>>>(MAX_QUEUE_SIZE);
 
std::shared_ptr<BoundedTSQueue<InferenceResult>> results_queue =
    std::make_shared<BoundedTSQueue<InferenceResult>>(MAX_QUEUE_SIZE);

// Task-specific preprocessing callback
void preprocess_callback(const std::vector<cv::Mat>& org_frames,
                         std::vector<cv::Mat>& preprocessed_frames,
                         uint32_t target_width, uint32_t target_height)
{
    preprocessed_frames.clear();
    preprocessed_frames.reserve(org_frames.size());

    for (const auto &src_bgr : org_frames) {
        // Skip invalid frames but keep vector alignment (optional: push empty)
        if (src_bgr.empty()) {
            preprocessed_frames.emplace_back();
            continue;
        }
        cv::Mat rgb;
        // 1) Convert to RGB
        if (src_bgr.channels() == 3) {
            cv::cvtColor(src_bgr, rgb, cv::COLOR_BGR2RGB);
        } else if (src_bgr.channels() == 4) {
            // If someone passed BGRA, drop alpha
            cv::cvtColor(src_bgr, rgb, cv::COLOR_BGRA2RGB);
        } else if (src_bgr.channels() == 1) {
            // If grayscale sneaks in, promote to 3 channels
            cv::cvtColor(src_bgr, rgb, cv::COLOR_GRAY2RGB);
        } else {
            // Fallback: force 3 channels by duplicating/merging
            std::vector<cv::Mat> ch(3, src_bgr);
            cv::merge(ch, rgb);
            cv::cvtColor(rgb, rgb, cv::COLOR_BGR2RGB); // ensure RGB order
        }
        // 2) Resize to target
        if (rgb.cols != static_cast<int>(target_width) || rgb.rows != static_cast<int>(target_height)) {
            cv::resize(rgb, rgb, cv::Size(static_cast<int>(target_width),
                                          static_cast<int>(target_height)),
                       0.0, 0.0, cv::INTER_AREA);
        }
        // 3) Ensure contiguous buffer
        if (!rgb.isContinuous()) {
            rgb = rgb.clone();
        }
        // 4) Push to output vector
        preprocessed_frames.push_back(std::move(rgb));
    }
}

// Task-specific postprocessing callback
void postprocess_callback(
    cv::Mat &frame_to_draw,
    const std::vector<std::pair<uint8_t*, hailo_vstream_info_t>> &output_data_and_infos,
    const VisualizationParams &vis)
{
    const size_t class_count = 3;
    float traffic_light_area[10] = {0};

    auto bboxes = parse_nms_data(output_data_and_infos[0].first, class_count);

    draw_bounding_boxes(frame_to_draw, bboxes, vis);

    // Show lidar points in their own window (mm scaled down to pixels), redrawn only when a new scan arrives
    static unsigned long last_lidar_seq = 0;
    unsigned long current_lidar_seq = Oradar_S2L_Get_Scan_Seq();
    if (current_lidar_seq != last_lidar_seq) {
        last_lidar_seq = current_lidar_seq;

        const int canvas_size = 1080;
        const float lidar_scale = 0.15f; // pixels per mm
        const int grid_spacing_mm = 500;
        const cv::Point origin(canvas_size / 2, canvas_size / 2);
        cv::Mat lidar_canvas(canvas_size, canvas_size, CV_8UC3, cv::Scalar(255, 255, 255));
        const cv::Scalar grid_color(180, 180, 180);
        const cv::Scalar axis_color(60, 60, 60);

        // Parallel grid lines every grid_spacing_mm, labeled in mm
        int max_offset_mm = (int)((canvas_size / 2) / lidar_scale);
        for (int offset_mm = grid_spacing_mm; offset_mm <= max_offset_mm; offset_mm += grid_spacing_mm) {
            int offset_px = (int)(offset_mm * lidar_scale);

            cv::line(lidar_canvas, cv::Point(origin.x + offset_px, 0), cv::Point(origin.x + offset_px, canvas_size), grid_color, 1);
            cv::line(lidar_canvas, cv::Point(origin.x - offset_px, 0), cv::Point(origin.x - offset_px, canvas_size), grid_color, 1);
            cv::line(lidar_canvas, cv::Point(0, origin.y + offset_px), cv::Point(canvas_size, origin.y + offset_px), grid_color, 1);
            cv::line(lidar_canvas, cv::Point(0, origin.y - offset_px), cv::Point(canvas_size, origin.y - offset_px), grid_color, 1);

            cv::putText(lidar_canvas, std::to_string(offset_mm), cv::Point(origin.x + offset_px + 2, origin.y - 2),
                        cv::FONT_HERSHEY_PLAIN, 0.8, grid_color, 1);
            cv::putText(lidar_canvas, std::to_string(offset_mm), cv::Point(origin.x - offset_px + 2, origin.y - 2),
                        cv::FONT_HERSHEY_PLAIN, 0.8, grid_color, 1);
        }

        // Crosshair axes drawn last so they stand out over the grid
        cv::line(lidar_canvas, cv::Point(origin.x, 0), cv::Point(origin.x, canvas_size), axis_color, 1);
        cv::line(lidar_canvas, cv::Point(0, origin.y), cv::Point(canvas_size, origin.y), axis_color, 1);

        // Mark the 0 degree direction (lidar angle index 0, along +x) distinctly from the plain axes
        const cv::Scalar zero_deg_color(0, 0, 255); // red
        cv::line(lidar_canvas, origin, cv::Point(canvas_size, origin.y), zero_deg_color, 2);
        cv::putText(lidar_canvas, "0deg", cv::Point(canvas_size - 60, origin.y - 8),
                    cv::FONT_HERSHEY_PLAIN, 1.0, zero_deg_color, 1);

        // Gather valid points (range + angle + cartesian mm) for ROR + breakpoint detection
        float lidar_buffer[360];
        Oradar_S2L_Get_Buffer(&lidar_buffer[0]);
        std::vector<cv::Point2f> points_mm;
        std::vector<float> point_range_mm;
        std::vector<float> point_angle_deg;
        points_mm.reserve(360);
        point_range_mm.reserve(360);
        point_angle_deg.reserve(360);
        for (int angle = 0; angle < 360; angle++) {
            if (lidar_buffer[angle] <= 0) continue;
            float x_mm = lidar_buffer[angle] * cos(Oradar_S2L_Grados_A_Radianes((float)angle));
            float y_mm = lidar_buffer[angle] * sin(Oradar_S2L_Grados_A_Radianes((float)angle));
            points_mm.emplace_back(x_mm, y_mm);
            point_range_mm.push_back(lidar_buffer[angle]);
            point_angle_deg.push_back((float)angle);
        }

        // Radius Outlier Removal (ROR): a point is an outlier if it has fewer than
        // ror_min_neighbors other points within ror_radius_mm of it.
        const float ror_radius_mm = 100.0f;
        const int   ror_min_neighbors = 10;
        std::vector<bool> is_outlier(points_mm.size(), false);
        for (size_t i = 0; i < points_mm.size(); i++) {
            int neighbor_count = 0;
            for (size_t j = 0; j < points_mm.size(); j++) {
                if (i == j) continue;
                if (cv::norm(points_mm[i] - points_mm[j]) <= ror_radius_mm) {
                    neighbor_count++;
                    if (neighbor_count >= ror_min_neighbors) break;
                }
            }
            is_outlier[i] = (neighbor_count < ror_min_neighbors);
        }

        // Adaptive Breakpoint Detector (Borges & Aldon): walk the ordered inlier points
        // and start a new wall segment whenever the gap to the previous point exceeds
        // the spacing expected for two returns off the same flat surface.
        // A smaller lambda shrinks sin(lambda-delta_phi) in D_max's denominator below,
        // which makes D_max *larger* - i.e. more tolerant of gaps, less likely to split.
        // At 5deg, D_max for a ~450mm-range point was ~142mm: generous enough that a
        // real object sitting near a wall wouldn't get split off as its own segment.
        const float bpd_lambda_deg = 10.0f;  // min incidence angle assumed for a flat surface
        const float bpd_sigma_r_mm = 10.0f;  // range measurement noise estimate
        const float lambda_rad = Oradar_S2L_Grados_A_Radianes(bpd_lambda_deg);
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
int main(int argc, char** argv)
{
    signal(SIGINT, signal_handler); /* Set interrupt for ctrl+C */
    Oradar_S2L_Init_Lidar();
    pthread_create(&writer, NULL, Oradar_S2L_Lidar_Writer_Thread, NULL);

    Rasp_Gpio_Init();
    Rasp_Gpio_Power_On_Spike();

    Spike_Serial_Init();
    Spike_Interpreter();
    Spike_Initialize_Libraries();
    pthread_create(&Main_Actions, NULL, Obstacle_Challenge_Thread, NULL);

    try {
        const std::string APP_NAME = "object_detection";
        std::chrono::duration<double> inference_time;
        auto t_start = Clock::now();

        double org_height, org_width;
        cv::VideoCapture capture;
        size_t frame_count;
        InputType input_type;

        CommandLineArgs args = parse_command_line_arguments(argc, argv);
        post_parse_args(APP_NAME, args, argc, argv);
        g_no_display = args.no_display;
        HailoInfer model(args.net, args.batch_size);

        // Load visualization config params
        VisualizationParams vis_param = load_visualization_params("/home/maker/WRO_Future_Engineers_Queretaro_CSS/software/cpp/object_detection/visualization_config.yaml");
        validate_visualization_params(vis_param, AppVisMode::object_detection);

        auto post_cb = std::bind(postprocess_callback,
                                 std::placeholders::_1,
                                 std::placeholders::_2,
                                 std::cref(vis_param));

        input_type = determine_input_type(args.input,
                                        std::ref(capture),
                                        std::ref(org_height),
                                        std::ref(org_width),
                                        std::ref(frame_count),
                                        std::ref(args.batch_size),
                                        std::ref(args.camera_resolution));

        auto preprocess_thread = std::async(run_preprocess,
                                            std::ref(args.input),
                                            std::ref(args.net),
                                            std::ref(model),
                                            std::ref(input_type),
                                            std::ref(capture),
                                            std::ref(args.batch_size),
                                            std::ref(args.framerate),
                                            preprocessed_batch_queue,
                                            preprocess_callback);

        ModelInputQueuesMap input_queues = {
            { model.get_infer_model()->get_input_names().at(0), preprocessed_batch_queue }
        };

        auto inference_thread = std::async(run_inference_async,
                                           std::ref(model),
                                           std::ref(inference_time),
                                           std::ref(input_queues),
                                           results_queue);

        auto output_parser_thread = std::async(run_post_process,
                                    std::ref(input_type),
                                    std::ref(org_height),
                                    std::ref(org_width),
                                    std::ref(frame_count),
                                    std::ref(capture),
                                    std::ref(args.framerate),
                                    std::ref(args.batch_size),
                                    std::ref(args.save_stream_output),
                                    std::ref(args.no_display),
                                    std::ref(args.output_dir),
                                    std::ref(args.output_resolution),
                                    results_queue,
                                    post_cb);

        hailo_status status = wait_and_check_threads(
            preprocess_thread,    "Preprocess",
            inference_thread,     "Inference",
            output_parser_thread, "Postprocess "
        );
        if (HAILO_SUCCESS != status) {
            return status;
        }
        
        auto t_end = Clock::now();
        print_inference_statistics(inference_time, args.net, static_cast<double>(frame_count), t_end - t_start);

        return HAILO_SUCCESS;
    }
    catch (const std::exception &e) {
        std::cerr << "ERROR: " << e.what() << "\n";
        return HAILO_INTERNAL_FAILURE;
    }
}

void *Obstacle_Challenge_Thread(void *arg){
    float distancia_frente;
    float distancia_derecha;
    float distancia_izquierda;
    float lidar_shared_buffer[360]; // Your shared buffer

    Oradar_S2L_Get_Buffer(&lidar_shared_buffer[0] );
    distancia_frente = lidar_shared_buffer[0];
    distancia_derecha = lidar_shared_buffer[270];
    distancia_izquierda = lidar_shared_buffer[90];

    printf("dsitancia derecha : %f\n", distancia_derecha);
    printf("dsitancia izquierda : %f\n", distancia_izquierda);
    printf("dsitancia frente : %f\n", distancia_frente);

    Spike_Reset_Gyro(0);
    Rasp_Gpio_Wait_For_Button();
    usleep(200000); //wiating for reset gyro
    Spike_Reset_Gyro(0);
    Spike_Center_Vehicle_Short();

    float slope = Slope(front);
    Spike_Reset_Gyro(slope);
    

    avoid_cube_start_section((Color_traffic_light)traffic_lights.light_color, cube_first);
    Spike_Center_Vehicle_Short();
    avoid_cube_start_section((Color_traffic_light)traffic_lights.light_color, cube_second);
    
    /*if(distancia_derecha > 600){
        printf("Sentido horario\n");
        Spike_Turn_For_Degrees(right, 60, 88, 40);


    }

    else if (distancia_izquierda > 600){
        printf("Sentido antihorario\n");
        Spike_Turn_For_Degrees(left, 60, 88, 40);

    
    }*/
   /* programa de christian
   Follow_cubes(60, 0.5, 0.06);
   float grados = Spike_Get_Gyro();
   Spike_Small_Turn(left, 60, 0, 30);
   Spike_Turn_For_Degrees(left, 60, grados + 30, 30);
   Spike_Center_Vehicle_Short();
   Spike_Advance_For_Degrees(60,30*abs(grados), 30);
   Spike_Small_Turn(right, 60, 0, 30);
   Spike_Center_Vehicle_Short();
   Follow_cubes(60, 0.5, 0.06);  
   grados = Spike_Get_Gyro();
   
   Spike_Turn_For_Degrees(right, 60, (grados*-1) + 30, 30);
   Spike_Center_Vehicle_Short();
   Spike_Advance_For_Degrees(60,30*abs(grados), -30);
   Spike_Small_Turn(left, 60, 0, 30);
   Spike_Center_Vehicle_Short();*/


   

   


    while(terminating_main == 0){
        /*Oradar_S2L_Get_Buffer(&lidar_shared_buffer[0] );
        distancia_izquierda = lidar_shared_buffer[90];
        printf("dsitancia izquierda : %f\n", distancia_izquierda);*/
        usleep(1000);
    }

    Spike_Coast_Motors();
    Oradar_S2L_Set_Terminating();
    Rasp_Gpio_Clean();
    Spike_Close_Serial();
    Oradar_S2L_Close();
    return NULL;
}

void Follow_cubes(int vel, float referencia_2, float area){

    while((terminating_main == 0) && (traffic_lights.area < area) && (traffic_lights.confidence > 0.8)){
        Spike_Follow_Reference(vel, traffic_lights.middle_point_x, referencia_2);
        usleep(1000);
    }
    Spike_Coast_Motors();

}

// Total-least-squares (PCA) line orientation, in degrees, through the given indices of pts.
static float Fit_Line_Orientation(const std::vector<cv::Point2f> &pts, const std::vector<int> &indices) {
    double mean_x = 0, mean_y = 0;
    for (int idx : indices) { mean_x += pts[idx].x; mean_y += pts[idx].y; }
    mean_x /= indices.size();
    mean_y /= indices.size();

    double sxx = 0, syy = 0, sxy = 0;
    for (int idx : indices) {
        double dx = pts[idx].x - mean_x;
        double dy = pts[idx].y - mean_y;
        sxx += dx * dx;
        syy += dy * dy;
        sxy += dx * dy;
    }
    return Oradar_S2L_Radianes_A_Grados(0.5 * atan2(2.0 * sxy, sxx - syy));
}

// RMS perpendicular distance of the indexed points to their own best-fit line: a direct
// measure of how "noisy" the segment is (low = points line up cleanly, high = scattered).
static float Line_Fit_Residual_Mm(const std::vector<cv::Point2f> &pts, const std::vector<int> &indices) {
    if (indices.size() < 2) return 0.0f;
    float theta_rad = Oradar_S2L_Grados_A_Radianes(Fit_Line_Orientation(pts, indices));
    double nx = -sin(theta_rad), ny = cos(theta_rad); // unit normal to the fitted line

    double mean_x = 0, mean_y = 0;
    for (int idx : indices) { mean_x += pts[idx].x; mean_y += pts[idx].y; }
    mean_x /= indices.size();
    mean_y /= indices.size();

    double sum_sq = 0;
    for (int idx : indices) {
        double r = (pts[idx].x - mean_x) * nx + (pts[idx].y - mean_y) * ny;
        sum_sq += r * r;
    }
    return (float)sqrt(sum_sq / indices.size());
}
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

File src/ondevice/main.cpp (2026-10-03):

 #include "spike.h"
#include "rasp_gpio.h"
#include "common_var.h"
#include <math.h>

#include "Oradar_S2L.h"

void signal_handler(int signum);

pthread_t writer;

int der = 1;
int izq = -1;

static float lidar_shared_buffer[360]; // Your shared buffer

// Debounce: solo se acepta una lectura cuando 3 muestras consecutivas
// difieren entre si por menos de 3 cm.
#define LIDAR_DEBOUNCE_SAMPLES 3
#define LIDAR_DEBOUNCE_TOLERANCE_MM 30.0f // 3 cm

static float Lidar_Debounced_Read(int angle_index){
    float samples[LIDAR_DEBOUNCE_SAMPLES];
    int count = 0;

    while(count < LIDAR_DEBOUNCE_SAMPLES){
        Oradar_S2L_Get_Buffer(&lidar_shared_buffer[0]);
        float value = lidar_shared_buffer[angle_index];

        if(count == 0 || fabsf(value - samples[count - 1]) <= LIDAR_DEBOUNCE_TOLERANCE_MM){
            samples[count] = value;
            count++;
        } else {
            samples[0] = value;
            count = 1;
        }
    }

    return samples[LIDAR_DEBOUNCE_SAMPLES - 1];
}

int main(){

    float distancia_frente;
    float distancia_derecha;
    float distancia_izquierda;
    direction sentido;
    int v = 0;
    int angulo_correccion = 0;
    int angulo_correccion_t = 0;
    int angulo_correccion_t2 = 0;

    signal(SIGINT, signal_handler); /* Set interrupt for ctrl+C */
    Oradar_S2L_Init_Lidar();
    
    pthread_create(&writer, NULL, Oradar_S2L_Lidar_Writer_Thread, NULL);
    
    Rasp_Gpio_Init();
    Rasp_Gpio_Power_On_Spike();
    Spike_Serial_Init();
    Spike_Interpreter();
    Spike_Initialize_Libraries();
    Rasp_Gpio_Wait_For_Button();
    Spike_Reset_Gyro(0);
    usleep(200000); //wiating for reset gyro
    Spike_Center_Vehicle_Short();

    //while(1){
      //  angulo_correccion_t = Oradar_S2L_Wall_Slope(LEFT);
       // usleep(100000);
        
    //}

    distancia_frente = Lidar_Debounced_Read(270);
    distancia_derecha = Lidar_Debounced_Read(0);
    distancia_izquierda = Lidar_Debounced_Read(180);

    printf("dsitancia derecha : %f\n", distancia_derecha);
    printf("dsitancia izquierda : %f\n", distancia_izquierda);
    printf("dsitancia frente : %f\n", distancia_frente);

    if((distancia_derecha > 800) || (distancia_izquierda > 800)){

        printf("caso afuera\n");

        sentido = Oradar_S2L_Advance_And_Detect_Side(80, 0);
        printf("sentido %d :\n", sentido);

        if(sentido == right){
            Spike_Turn_For_Degrees(der, 100, 70);
            Spike_Center_Vehicle_Short();
            Spike_Advance_For_Degrees(100, 1350, -90);
            angulo_correccion = Oradar_S2L_Wall_Slope(LEFT);
            Spike_Reset_Gyro(angulo_correccion);
            usleep(200000);
            while (v < 11){
            Oradar_S2L_Advance_Until_Right_Gap(100, 0);
            Spike_Turn_For_Degrees(der, 100, 70);
            Spike_Center_Vehicle_Short();
            Spike_Advance_For_Degrees(100, 600, -90);
            angulo_correccion = Oradar_S2L_Wall_Slope(LEFT);
            Spike_Reset_Gyro(angulo_correccion);
            usleep(200000);
            v = v + 1;
            }

        }
        else if (sentido == left)
        {
            Spike_Turn_For_Degrees(izq, 100, 70);
            Spike_Center_Vehicle_Short();
            Spike_Advance_For_Degrees(100, 1350, 90);
            angulo_correccion = Oradar_S2L_Wall_Slope(RIGHT);
            Spike_Reset_Gyro(angulo_correccion);
            usleep(200000);
            while (v < 11){
            Oradar_S2L_Advance_Until_Left_Gap(100, 0);
            Spike_Turn_For_Degrees(izq, 100, 70);
            Spike_Center_Vehicle_Short();
            Spike_Advance_For_Degrees(100, 600, 90);
            angulo_correccion = Oradar_S2L_Wall_Slope(RIGHT);
            Spike_Reset_Gyro(angulo_correccion);
            usleep(200000);
            v = v + 1;
            }

        }
    }

    else{

        printf("caso adentro\n");

        sentido = Oradar_S2L_Advance_And_Detect_Side(80, 0);
        printf("sentido : %d \n", sentido);

        if(sentido == right){
            Spike_Turn_For_Degrees(der, 100, 70);
            Spike_Center_Vehicle_Short();
            Spike_Advance_For_Degrees(100, 600, -90);
            angulo_correccion = Oradar_S2L_Wall_Slope(LEFT);
            Spike_Reset_Gyro(angulo_correccion);
            usleep(200000);
            while (v < 11){
            Oradar_S2L_Advance_Until_Right_Gap(100, 0);
            Spike_Turn_For_Degrees(der, 100, 70);
            Spike_Center_Vehicle_Short();
            Spike_Advance_For_Degrees(100, 600, -90);
            angulo_correccion = Oradar_S2L_Wall_Slope(LEFT);
            Spike_Reset_Gyro(angulo_correccion);
            usleep(200000);
            v = v + 1;
            }

        }
        else if (sentido == left)
        {
            Spike_Turn_For_Degrees(izq, 100, 70);
            Spike_Center_Vehicle_Short();
            Spike_Advance_For_Degrees(100, 600, 90);
            angulo_correccion = Oradar_S2L_Wall_Slope(RIGHT);
            Spike_Reset_Gyro(angulo_correccion);
            usleep(200000);
            while (v < 11){
            Oradar_S2L_Advance_Until_Left_Gap(100, 0);
            Spike_Turn_For_Degrees(izq, 100, 70);
            Spike_Center_Vehicle_Short();
            Spike_Advance_For_Degrees(100, 600, 90);
            angulo_correccion = Oradar_S2L_Wall_Slope(RIGHT);
            Spike_Reset_Gyro(angulo_correccion);
            usleep(200000);
            v = v + 1;
            }
        }
    } 

    /*if (sentido == right){
        if(distancia_izquierda < 400){
            Oradar_S2L_Advance_Until_Distance(80, 0, 450);
            printf("seccion por fuera\n");
        }   
        else if((distancia_izquierda > 400) && (distancia_izquierda < 600)){
            Oradar_S2L_Advance_Until_Distance(80, 0, 750);
            printf("en medio\n");
        }  
        else if (distancia_izquierda > 600){
            Oradar_S2L_Advance_Until_Distance(80, 0, 1000);
        printf("seccion por dentro\n");
        }

        Spike_Turn_For_Degrees(der, 100, 70);
        Spike_Center_Vehicle_Short();
        Spike_Advance_For_Degrees(80, 300, -90);

        if(distancia_frente < 1500){
            Oradar_S2L_Advance_Until_Distance(80, -90, 1400);
            printf("parte de adelante\n");
        }
        else if(distancia_frente > 1500){
            Oradar_S2L_Advance_Until_Distance(80, -90, 1850);
        printf("parte de atras\n");
        }
    }

    else if (sentido == left){
        if(distancia_derecha < 400){
            Oradar_S2L_Advance_Until_Distance(80, 0, 450);
            printf("seccion por fuera\n");
        }   
        else if((distancia_derecha > 400) && (distancia_derecha < 600)){
            Oradar_S2L_Advance_Until_Distance(80, 0, 750);
            printf("en medio\n");
        }  
        else if (distancia_derecha > 600){
            Oradar_S2L_Advance_Until_Distance(80, 0, 1000);
            printf("seccion por dentro\n");
        }
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

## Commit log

2026-03-15 Development of the spike and raspberry functions in c
    We carry out the part of the code that creates all the internal functions of the spike via serial for later use in raspberry functions, we begin to perform the raspberry functions that control the ev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
2026-03-21 Add KiCad schematics, bridge automation, docs, and ERC reports
    [can.kicad_sch, connectors.kicad_sch, debug.kicad_sch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]
2026-03-21 Spike improvements
    March 21st 2026. The exclusive functions of the spike were finished implementing, such as advancing by degrees or turning, the relay was added to turn on the spike along with the button that waits fo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
2026-03-22 RPLidar implementation
    We use the sdk(https://github.com/Slamtec/rplidar_sdk.git) examples to perform the functions of lidar initialization, reading Lidar points and we create the thread corresponding to lidar for constant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
2026-03-29 Lidar functions
    today we are dedicated to developing the lidar functions to orient ourselves on the track, together with the gyroscope we create an orientation system that restarts every time it makes a turn and is corrected with a function that detects the error (which sticks or sticks so much). detach the robot from the wall)
    [main.cpp, spike.cpp]
2026-04-05 Open Challenge update
    Today the first version of the Open Challenge was programmed using the RPLidar and spike functions that were done previously, our main orientation tool is the calculation of the slope with the lidar 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
2026-05-02 Obstacle Challenge and improvements of the Open Challenge
    Improvements were made to challenge 1 making lidar correction safer. We started challenge 2, we compiled the hailo-apps library to use the Raspberry Pi AI HAT+ (26 TOPS), our programs and libraries were added to the example to start using our model and functions
    [RPLidar_S2L.cpp, main.cpp, object_detection.cpp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]
2026-05-09 Cube follower
    In the obstacle challenge we develop a cube tracker that uses the camera to determine a position of where the cube is and thus follow it
2026-06-26 Improvement in Lidar Processing
    inprovement in lidar data filtering using wall detection
2026-07-04 Lidar detection improvement
    add wall detection and filter abnormal points
2026-07-25 mechanical Design in SOLIDWORKS
    New vehicle design with printed based
    [18650.SLDPRT, 1P Holder.SLDPRT, 32270Technic Gear 12 Tooth Double Bevel v1.SLDPRT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]
2026-08-05 Software hailo10 raspberry
    add library for hailo 10 HAT raspberry pi, adapt all the dependencies from hailo 8l hat to hailo 10 hat, keep the rest of the files unchanged. add new logic for object detection for areas
2026-08-05 Software hailo10 raspberry
    add build folder
2026-08-08 improvements from the first challenge
    Improvements were made to the lidar program oradar and RPLidar to be able to measure the inclination of the cart with respect to the wall through the first degree least squares function
2026-08-09 CAD design
    Improvements to the design of the car used by Lego Spike
    [32270Technic Gear 12 Tooth Double Bevel v1.SLDPRT, Base.SLDPRT, Grove relay v1.2 (1).SLDASM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]
2026-08-14 Change in car design
    In the design, the height of the lidar was adjusted so that it can see the 10cm walls of the runway
    [32270Technic Gear 12 Tooth Double Bevel v1.SLDPRT, Ackerman 2.SLDPRT, Base.SLDPRT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]
2026-08-15 Open challenge improvements with the MS200 lidar
2026-08-30 Fixed files reorganisation to fulfill git requirements
    [18650.SLDPRT, 1P Holder.SLDPRT, 32270Technic Gear 12 Tooth Double Bevel v1.SLDPRT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]
2026-09-07 Added Bill of Materials (BOM) to README.md
2026-09-07 Changes to the Obstacle Challenge code
    Chemages were made in the abstract challenge code in addition to adding some code flowcharts
2026-09-08 Added detailed Setup & Execution Instructions to README.md
    [results.csv]
2026-09-08 Updated flowcharts in README.md
2026-09-08 Stl files & final cad design
    [18650.SLDPRT, 1P Holder.SLDPRT, 32270Technic Gear 12 Tooth Double Bevel v1.SLDPRT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]
2026-09-08 Assembly instructions
2026-09-08 Assembly instructions update
2026-10-05 Run the open challenge (reto 1) on the Hiwonder board
    Replace the SPIKE hub with the Hiwonder STM32 controller (firmware
    pos-v8) in src/ondevice. main.cpp keeps its challenge logic; only the
    startup changes: Spike_Hiwonder_Init() opens the board, centers the
    steering and calibrates the gyro, replacing the relay pulse and the
    MicroPython REPL upload. This robot has no relay.
    spike.h now exposes the team's SPIKE API on top of spike_compat, vendored
    from hiwonder_brick into src/ondevice/hiwonder. spike_hiwonder.cpp
    translates the calls whose signature or units differ from the hub:
    - Spike_Reset_Gyro(int) takes decidegrees, like the hub's reset_yaw().
    Oradar_S2L_Wall_Slope() already returns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
    [hiwonder_brick.cpp, hiwonder_brick.hpp, main.cpp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]
2026-10-11 Support the Hailo-8 + RPLidar S2L robot in the Hiwonder H10 variant
    object_detection_hiwonder_h10 now builds for two robots:
    - H10: Hailo-10H + Oradar MS200 (build/h10_hiwonder, as before).
    - Hailo-8 HAT (26 TOPS) + RPLidar S2L: cmake -DWRO_LIDAR=RPLIDAR_S2L into
    build/h8_s2l, launched with run_hiwonder_h8.sh and the new Hailo-8 model
    src/HailoModels/yolov8n_wro_hailo8.hef (greenbox, redbox, xparking).
    The S2L driver fills the same 360-entry buffer, in the Oradar orientation,
    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
2026-11-08 Open challenge improvement
    Update open challenge to work with new vehicle, using the Hiwonder board as main Motor controler
2026-11-09 Partial International Final documentation (design v7): README, engineering journal, wiring diagram, BOM, test log, CAD v7
2026-11-09 International Final documentation (design v7): README, engineering journal, wiring diagram, BOM, test log, CAD v7, English code comments
2026-11-09 Comment v7 source code in English; steering limit ±35° in code, README and journal; release notes alpha.3
2026-11-09 Documentation feature-complete: power calculations, CAD views, datasheets, English docs
2026-11-10 Add v7 STL files and print profiles; English assembly instructions; fix build from a fresh clone; national round videos on YouTube
